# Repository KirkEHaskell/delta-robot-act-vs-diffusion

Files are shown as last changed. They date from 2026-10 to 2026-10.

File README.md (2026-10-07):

# ACT vs. Diffusion Policy on a Home-Built Delta Robot

**A real-robot comparison of the two most widely used imitation-learning policies, scaled across
training data (10–100 demonstrations) and training length (5k–50k steps), on a 3-DOF delta robot
with an electromagnet gripper. Everything is open: CAD, firmware, recording and evaluation code,
the 100-episode LeRobot dataset, 240 scored real-world trials, and the two best checkpoints.**

<p align="center">
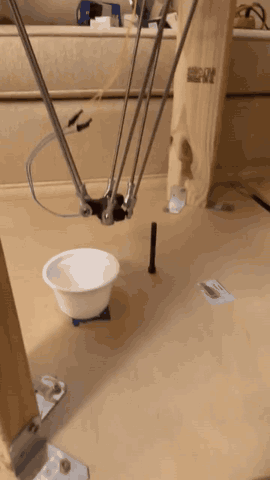
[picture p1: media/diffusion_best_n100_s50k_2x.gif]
Diffusion Policy (100 demos, 50k steps, 10/10 in scoring) picking up a bolt and dropping it in the cup, 2x speed
  
  &nbsp;&nbsp;
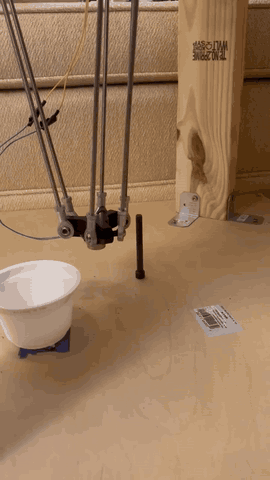
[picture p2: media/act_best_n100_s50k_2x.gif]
ACT (100 demos, 50k steps, 6/10 in scoring) picking up a bolt and dropping it in the cup, 2x speed
  
  <br>
  <sub>The two published models, fully autonomous, 2× speed, both trained on 100 demos for 50k steps and recorded after
  the study. Left: Diffusion Policy v2 (10/10 in scoring), RTX 3090. Right: ACT (6/10 in scoring), laptop CPU.
  Full-resolution clips: <a href="media/diffusion_best_n100_s50k.mp4">left</a>, <a href="media/act_best_n100_s50k.mp4">right</a>.
  Runs filmed during evaluation: <a href="media/diffusion_n25_s20k.mp4">Diffusion 25 demos / 20k</a>,
  <a href="media/act_n50_s20k.mp4">ACT 50 demos / 20k</a>.</sub>
</p>

<p align="center">
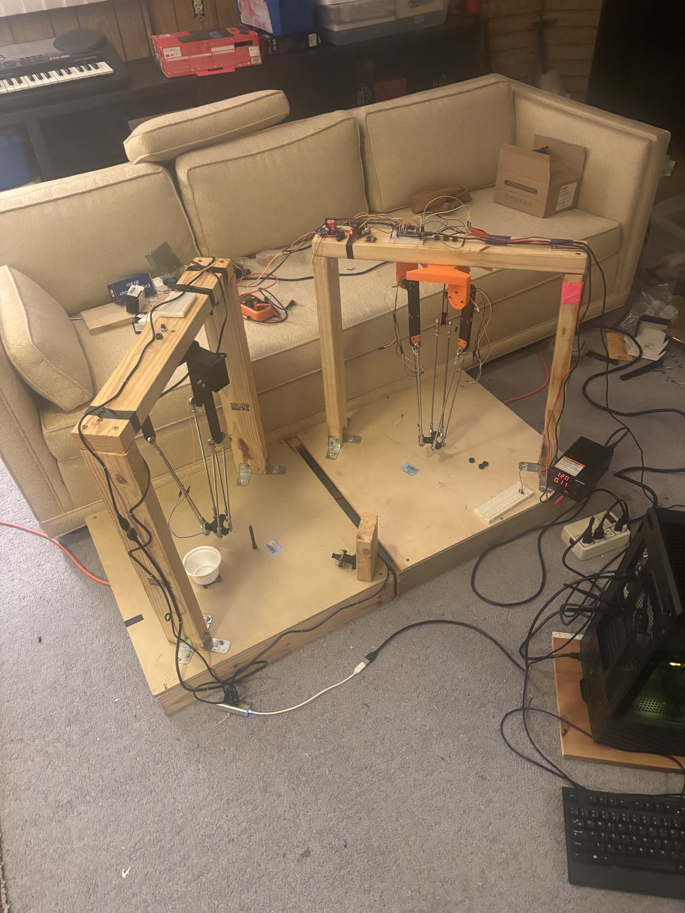
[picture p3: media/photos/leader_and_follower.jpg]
The follower robot (left, black, with the cup and bolt) and the hand-moved leader arm (right, orange mounts) side by side
  
  <br>
  <sub>The two robots. Left: the servo-driven follower that the policies control. Right: the leader arm, moved by hand
  during teleoperation, with a magnetic encoder at each shoulder.
  More photos: <a href="hardware/photos.md">hardware/photos.md</a>.</sub>
</p>

The task: find a steel bolt standing on the table, pick it up with the electromagnet, carry it to
a cup and drop it in. The policy sees three 320×240 USB cameras and outputs joint angles plus a
magnet on/off command at 30 Hz. There is no hand-written motion planning.

| | |
|---|---|
| Robot | 3-DOF delta robot, 3× Feetech STS3215 (12 V) servos, Teensy 4.1, electromagnet end effector |
| Teleoperation | Leader–follower: a second, hand-moved delta arm with 3× AS5600 magnetic encoders that the follower mirrors |
| Dataset | 100 demonstrations, 33,200 frames, 30 fps, 3 RGB cameras, LeRobot v3.0 format |
| Policies | ACT and Diffusion Policy, LeRobot 0.5.0 |
| Grid | {10, 25, 50, 100} demos × {5k, 20k, 50k} steps × 2 policies = 24 models |
| Evaluation | 10 real-robot trials per model (5 bolt positions × 2), **240 scored trials** |

📄 **Paper: [PDF](paper/ACT_vs_Diffusion_in_Delta_Robots_for_Simple_Pick_and_Place_Training.pdf)** (LaTeX source in [`paper/`](paper/)) · Markdown version: [REPORT.md](REPORT.md)

## Results at a glance

Success = the bolt ends up in the cup. 10 trials per cell.

| Demos | ACT 5k | ACT 20k | ACT 50k | Diffusion* 5k | Diffusion* 20k | Diffusion* 50k |
|---:|:---:|:---:|:---:|:---:|:---:|:---:|
| 10 | 0 | 0 | 0 | 0 | 0 | 2 |
| 25 | 0 | 6 | 2 | 1 | **8** | 5 |
| 50 | 1 | 6 | 5 | 2 | 4 | 1 |
| 100 | 0 | 3 | **6** | 0 | 6 | **10** |

<sub>*Diffusion Policy with four changes from LeRobot's defaults. The defaults did not work on this robot; see the first finding below.</sub>

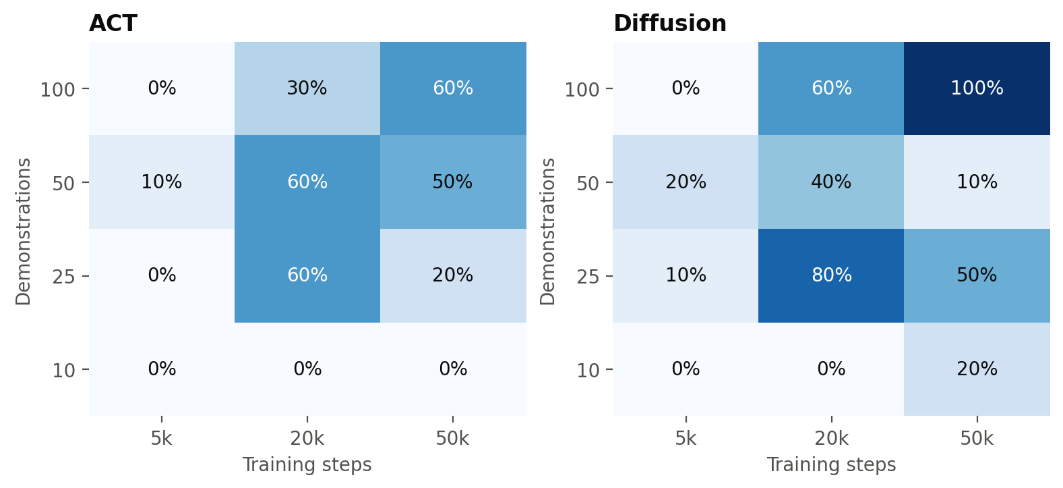
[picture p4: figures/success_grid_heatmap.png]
Success-rate heatmaps for ACT and Diffusion Policy


**Findings**

1. **Out of the box, LeRobot's Diffusion Policy never left the start pose.** With leader–follower
   teleoperation data, "next action ≈ current joint state" is almost exactly true. The default
   Diffusion setup (vision encoder trained from scratch, no crop augmentation, 2 observation frames,
   a 0.53 s horizon) learned to copy its own joint readings instead of looking at the cameras. Offline
   input-ablation tests showed this. Four changes fixed it: an ImageNet-pretrained ResNet-18, random crops,
   the joint-state input **blinded** (zeroed), and a 1.6 s action horizon. ACT, with its defaults, did
   not have this problem. If you train on leader–follower data, check for this shortcut.
2. **The best model was the fixed Diffusion Policy with 100 demos and 50k steps: 10/10**, every
   bolt position, every time on the first grab. Subjectively it was also the most impressive
   policy in the study. The operator's note was "just crushed it."
3. **Below about 20k steps or 25 demos, almost nothing works.** At 5k steps the two policies went 4/80
   combined, and with 10 demos 2/60.
4. **ACT improves steadily with more data** at 50k steps: 0 → 2 → 5 → 6 of 10 for 10/25/50/100 demos
   (trend p = 0.0015).
5. **There is no statistically significant overall winner.** Pooled over all 12 cells, Diffusion went
   39/120 and ACT 29/120 (Fisher p = 0.20). The two policies failed differently: ACT mostly knocked the
   bolt over (an aggressive grab); Diffusion mostly stalled (hesitation).
6. **ACT is the practical choice when speed matters.** It plans a 100-action chunk in about 0.1–0.4 s on a
   laptop CPU and runs in real time. Diffusion with 100 denoising steps needs about 0.76 s per
   24-action plan on an RTX 3090 (the robot pauses to think), and about 18 s on a laptop CPU.

Caveats: 10 trials per cell gives wide confidence intervals, and ACT and Diffusion were evaluated on
different machines on different days. [REPORT.md](REPORT.md) covers this in full.

## Models and dataset (Hugging Face)

| | Link | Trials | Notes |
|---|---|---|---|
| Dataset | [`KirkHaskell/delta_robot_bolt_pick_place`](https://huggingface.co/datasets/KirkHaskell/delta_robot_bolt_pick_place) | — | 100 episodes, LeRobot v3.0, 3 cameras, ~600 MB |
| Best Diffusion | [`KirkHaskell/diffusion_delta_robot_bolt_pick_place`](https://huggingface.co/KirkHaskell/diffusion_delta_robot_bolt_pick_place) | 10/10 | 100 demos, 50k steps; needs a GPU for real-time use |
| Best ACT | [`KirkHaskell/act_delta_robot_bolt_pick_place`](https://huggingface.co/KirkHaskell/act_delta_robot_bolt_pick_place) | 6/10 | 100 demos, 50k steps; runs on a laptop CPU |

The other 22 checkpoints (about 15 GB for the final checkpoints, about 250 GB with intermediate
checkpoints) are not published. Open an issue if you need one.

## What's in this repo

| Path | Contents |
|---|---|
| [`paper/`](paper/) | LaTeX source of the paper, its references and vector figures (`analysis/make_paper_figures.py`) |
| [`hardware/`](hardware/) | STL files for the printed parts and the Onshape assembly export (URDF + glTF meshes) |
| [`firmware/`](firmware/) | Teensy 4.1 firmware: leader–follower teleoperation, autonomous mode, electromagnet control |
| [`robot/`](robot/) | Record demonstrations, run a policy on the robot, scored evaluation sessions, camera and hardware checks (Windows + Linux) |
| [`training/`](training/) | Training queue for the whole grid, plus a LeRobot 0.5.0 wrapper (subset-sampler bug fix and joint-state blinding) |
| [`analysis/`](analysis/) | Results statistics and figures, the "copycat" diagnostic, DDIM-vs-DDPM check |
| [`results/`](results/) | All 240 trials, per-model summary, statistics, training-loss curves, ACT run traces |
| [`figures/`](figures/) | Plots used in the report |
| [`media/`](media/) | Robot videos and three example demonstrations (all three cameras side by side) |
| [`tools/`](tools/) | `render_episode.py`: turn any episode into a side-by-side video |

Example demonstrations from the dataset (left to right: `side`, `top_right`, `top_left`):
[episode 1](media/demos/episode_001.mp4) · [episode 42](media/demos/episode_042.mp4) · [episode 91](media/demos/episode_091.mp4)

## Quick start

Python 3.12 is recommended. Install PyTorch for your machine first (see pytorch.org), then:

```bash
git clone https://github.com/KirkEHaskell/delta-robot-act-vs-diffusion
cd delta-robot-act-vs-diffusion
pip install -r requirements.txt
```

**Download the dataset and the models**

```bash
hf download --repo-type dataset KirkHaskell/delta_robot_bolt_pick_place --local-dir data/delta_robot_bolt_pick_place
hf download KirkHaskell/act_delta_robot_bolt_pick_place --local-dir models/act
hf download KirkHaskell/diffusion_delta_robot_bolt_pick_place --local-dir models/diffusion
```

**Look at a demonstration** (needs ffmpeg)

```bash
python tools/render_episode.py --root data/delta_robot_bolt_pick_place --episode 42 --out episode_042.mp4
```

**Run a model on the robot** (from inside `robot/`, with the Teensy flashed and the cameras mapped; see [Building your own](#building-your-own))

```bash
cd robot
python teensy_check.py
python run_policy.py dry --ckpt ../models/act
python run_policy.py try --ckpt ../models/act
```

`dry` runs the model on live inputs and prints its actions without moving the robot. `try` runs it
for real: Enter starts a run and Space stops it. Diffusion: add `TC_SCHED=DDIM TC_STEPS=10` on a
CPU-only machine (much slower, but it works). The joint-state blinding the Diffusion model needs is
applied automatically.

**Train your own**

```bash
python training/run_grid.py --console          # the full ACT grid + default Diffusion (v1)
python training/run_grid.py --v2 --console     # the fixed Diffusion grid (v2)
```

Or train a single model with the same settings as the best Diffusion model:

```bash
BLIND_STATE=1 python training/lerobot_train_fixed.py \
  --dataset.repo_id=local/delta_robot_bolt_pick_place --dataset.root=data/delta_robot_bolt_pick_place \
  --dataset.video_backend=pyav --policy.type=diffusion --policy.push_to_hub=false \
  --policy.pretrained_backbone_weights=ResNet18_Weights.IMAGENET1K_V1 --policy.use_group_norm=false \
  "--policy.crop_shape=[216, 288]" --policy.crop_is_random=true --policy.n_obs_steps=1 \
  --policy.horizon=48 --policy.n_action_steps=24 --policy.drop_n_last_frames=24 \
  --batch_size=32 --seed=1000 --steps=50000 --output_dir=outputs/diffusion_v2_n100
```

For ACT, use `--policy.type=act` and drop the Diffusion-specific flags and `BLIND_STATE`. Training
used one RTX 3090. Expect about 3 h for 50k steps of either policy at batch size 32.

## Building your own

This repo is not a step-by-step build guide, but everything needed to reproduce the robot is here:

- **Printed parts:** [`hardware/stl/`](hardware/stl/) (base, upper arms, end effector with electromagnet
  mount, camera holders). [`hardware/onshape_export/`](hardware/onshape_export/) has the full assembly
  as URDF + glTF.
- **Electronics:**
  - Teensy 4.1
  - 3× Feetech STS3215 servos on a 1 Mbit/s bus (Teensy `Serial1`, servo IDs 2, 3, 1)
  - 3× AS5600 magnetic encoders on the leader arm (two hardware I²C buses + one bit-banged bus)
  - an electromagnet driven through an H-bridge (pins 30/32)
  - a push button for the magnet during teleoperation (pins 4/5)
  - 3× Innomaker U20CAM-720P USB cameras on a USB hub

  Pin assignments and calibration constants are at the top of
  [`firmware/delta_teleop/delta_teleop.ino`](firmware/delta_teleop/delta_teleop.ino).
- **Software setup:**
  1. Flash the firmware. Calibrate the encoders with the `d` debug command, as described in the
     firmware comments.
  2. Map each camera's USB port to its role in `robot/cameras_windows.py` or `robot/cameras_linux.py`.
     Run that file to list the ports.
  3. Check everything with `python robot/teensy_check.py` and `python robot/view_cameras.py`.
  4. Record demonstrations with `python robot/record_demos.py --root ../data/my_dataset`.
- **Serial protocol** (USB, 115200 baud):

  | Command | Meaning |
  |---|---|
  | `s` | Record/teleop mode |
  | `a` | Autonomous mode |
  | `c,j1,j2,j3,magnet` | Move command (autonomous mode) |
  | `x` | Stop |
  | `d` | Debug dump |

  The Teensy streams `millis,leader×3,follower×3,magnet` at 60 Hz. Joint angles are in degrees,
  clamped to 30–110°.

**Will the published checkpoints work on my robot?** Probably not without fine-tuning. They are tied
to this exact camera placement, table, lighting and camera colour settings. Treat them as a
reference point and as a starting point for fine-tuning on your own demos. The dataset and code are
the reusable parts.

**Camera colour:** in all of the training data, the `side` and `top_right` cameras have a
yellow-green cast. An old OpenCV script had turned auto white balance off and fixed the exposure,
and Windows kept those settings. The models expect this. On Linux, `run_policy.py` reproduces it
through V4L2 controls. For your own data, record with the cameras on auto
(`TC_MATCH_TRAINING_CAMERAS=0`).

## Lessons learned

- **Check that your policy actually uses the cameras.** [`analysis/diag_copycat.py`](analysis/diag_copycat.py)
  replays demos with the joint state frozen, then with the images frozen. A healthy policy
  reproduces the motion from images alone; a "copycat" doesn't. Low validation loss does not detect
  this.
- **Training loss predicts nothing here.** Fewer demos always gave lower loss (memorization) and
  worse robot performance.
- **LeRobot 0.5.x moved normalization out of the policy.** At inference you must load the
  checkpoint's pre/post-processors (`make_pre_post_processors`). Otherwise the actions come out
  normalized, and the arm drives into a joint limit.
- **LeRobot 0.5.0 bug:** Diffusion training with `--dataset.episodes` crashes, or silently reads the
  wrong frames. `training/lerobot_train_fixed.py` patches the sampler.
- **Three USB cameras on one hub need MJPG.** OpenCV on Windows silently falls back to uncompressed
  YUY2 and starves the third camera. Capture with PyAV and force MJPG.

## Citation

```bibtex
@misc{delta_act_vs_diffusion_2026,
  title  = {ACT vs. Diffusion Policy on a Home-Built Delta Robot: Data and Training-Length Scaling for Real-World Pick-and-Place},
  author = {Kirk Haskell},
  year   = {2026},
  url    = {https://github.com/KirkEHaskell/delta-robot-act-vs-diffusion}
}
```

## License

- **Code and firmware:** [MIT](LICENSE)
- **Dataset, CAD files, videos and figures:** [CC BY 4.0](LICENSE-DATA.md).
  Free to use, including commercially and for training models, with attribution.

Built with [LeRobot](https://github.com/huggingface/lerobot). The policies are
[ACT](https://arxiv.org/abs/2304.13705) (Zhao et al., 2023) and
[Diffusion Policy](https://arxiv.org/abs/2303.04137) (Chi et al., 2023).

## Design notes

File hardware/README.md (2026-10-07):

# Hardware

3D-printable parts and the full CAD assembly of the delta robot. This is not a step-by-step build
guide; see [photos.md](photos.md) and the videos in `media/` for how the parts go together.

## `stl/`: printed parts

| File | Part |
|---|---|
| `base_part1.stl`, `base_part2.stl` | Base, in two pieces |
| `upper_arm_6in_12mm.stl` | Upper arm driven by each servo ("Shoulder6in(12mm)" in the CAD); print 3 |
| `end_effector_electromagnet.stl` | End-effector platform with the electromagnet mount |
| `camera_holder.stl` | Camera mount |
| `camera_holder_base_mount.stl` | Camera mount that attaches to the base |

## `onshape_export/`

The Onshape assembly exported as **URDF + glTF meshes** (`assembly_1/urdf/assembly_1.urdf`, with a
ROS launch file). Delta robots are closed kinematic chains, so the URDF contains `*_loop_closure`
links from Onshape's export. Simulators that need a tree (e.g. plain ROS `robot_state_publisher`)
will only show the open part of each chain.

## Electronics (as built)

| Part | Notes |
|---|---|
| Teensy 4.1 | Runs `firmware/delta_teleop/delta_teleop.ino` |
| 3× Feetech STS3215 | Serial-bus servos on `Serial1` (TX pin 1 / RX pin 0), 1 Mbit/s, IDs 2, 3, 1 |
| 3× AS5600 magnetic encoder | Leader arm (teleoperation only). Two hardware I²C buses (`Wire`, `Wire2`) + one bit-banged bus on pins 20/21 |
| Electromagnet (~12 V) + H-bridge | IN1 = pin 30, IN2 = pin 32 |
| Push button | Magnet control during teleoperation, between pins 4 and 5 |
| 3× Innomaker U20CAM-720P | USB cameras on one hub, captured as MJPG 320×240 @ 30 fps |

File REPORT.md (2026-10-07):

# ACT vs. Diffusion Policy on a Home-Built Delta Robot: Data and Training-Length Scaling for Real-World Pick-and-Place

**Kirk Haskell** · October 2026 · Code, CAD, data and models: <https://github.com/KirkEHaskell/delta-robot-act-vs-diffusion>

---

## Abstract

We trained imitation-learning policies for a 3-DOF delta robot with an electromagnet gripper. The
task is to pick up a standing bolt and drop it into a cup. We compared **ACT** (Action Chunking with
Transformers) and **Diffusion Policy** along two axes: the amount of training data (10, 25, 50 or 100
teleoperated demonstrations) and the training length (5k, 20k or 50k optimizer steps). That is 24
models in total, each scored on 10 real-robot trials (240 trials).

Out of the box, LeRobot's default Diffusion Policy **did not move**. It had learned to copy the
robot's own joint state rather than use its cameras, a shortcut that leader–follower teleoperation
data makes very attractive. We diagnosed this with offline input-ablation tests and fixed it with
four changes:

- an ImageNet-pretrained vision encoder
- random-crop augmentation
- the joint-state input blinded (zeroed)
- a 1.6 s action horizon

With these changes, the best model, **Diffusion Policy with 100 demos and 50k steps, succeeded on
10/10 trials**. The best ACT models reached 6/10.

Both policies essentially failed with 10 demonstrations or with 5k training steps. ACT showed a
clean data-scaling trend at 50k steps (0 → 20 → 50 → 60%). Pooled over the grid, Diffusion succeeded
on 33% of trials and ACT on 24%, a difference that is not statistically significant (p = 0.20). The
two policies failed in different ways: ACT mostly knocked the bolt over, while Diffusion mostly
stalled. ACT ran in real time on a laptop CPU, while Diffusion needed a desktop GPU and paused while
planning.

---

## 1. Introduction

Imitation learning from teleoperated demonstrations is now the standard way to teach low-cost robot
arms manipulation skills. Two policy classes dominate open-source practice: ACT [1] and Diffusion
Policy [2], both implemented in Hugging Face's LeRobot library [3]. People adopting them face two
practical questions:

1. **How many demonstrations do I need?**
2. **How long should I train?**

Published comparisons mostly use standard arms (ALOHA, Franka, SO-100) and report a single
data/compute setting. This study measures a full 4 × 3 grid of data and training length for both
policies on a physically different robot, a **delta (parallel) robot**. It scores every model on the
real robot under a fixed protocol.

**Contributions**

- A controlled real-robot grid: 2 policies × 4 data sizes × 3 training lengths, 240 scored trials,
  with the raw trial log, statistics and code to regenerate every number.
- A documented failure mode: default Diffusion Policy learns a **proprioception "copycat" shortcut**
  from leader–follower data. The report gives an offline diagnostic for it and a fix.
- An open dataset (100 demonstrations, 3 cameras, LeRobot v3.0) for a delta robot with a binary
  magnetic gripper, an embodiment that is rare in public robot-learning datasets.
- Open hardware (STL/URDF), firmware, and recording/evaluation software.

## 2. System

### 2.1 Robot

- **Arm:** a 3-DOF delta robot. Three printed upper arms are driven by **Feetech STS3215** serial-bus
  servos, and steel parallelogram rods with ball joints connect them to the end effector.
- **End effector:** an electromagnet (~12 V) switched through an H-bridge, which lifts the steel bolt.
- **Controller:** a **Teensy 4.1** talks to the servos over a 1 Mbit/s half-duplex bus.
- **Joint limits:** commands are clamped to 30–110°.

Joint angles are reported in degrees. The firmware, 3D-printed parts and the Onshape assembly
(URDF + meshes) are in `firmware/` and `hardware/`.

### 2.2 Teleoperation

Demonstrations were collected **leader–follower**. The operator moves a passive leader arm whose
three joints carry **AS5600** magnetic encoders, and the Teensy drives the follower servos to the
same angles in real time. A push button on the leader switches the magnet. The Teensy streams
`(leader angles, follower angles, magnet state)` at 60 Hz, and the recorder samples it at 30 Hz.

### 2.3 Cameras

The robot uses three **Innomaker U20CAM-720P** USB cameras: `side`, `top_right` and `top_left`.
All three are captured at 320×240, 30 fps, MJPG. Two practical details mattered:

- **Bandwidth.** Three uncompressed (YUY2) streams saturate one USB hub. OpenCV's Windows backend
  cannot force MJPG, so capture goes through PyAV/ffmpeg with MJPG forced. Cameras are addressed by
  physical USB port rather than OS index, because the indices reshuffle on replug and all three
  cameras share one serial number.
- **Colour cast.** In all recorded data, `side` and `top_right` have a strong yellow-green cast. An
  old OpenCV script had disabled auto white balance (left at 4600 K) and fixed the exposure at
  2⁻⁶ s, and Windows persisted those settings per device. `top_left` ran on auto. The cast is
  constant across the dataset. For evaluation on Linux it was reproduced exactly through V4L2
  controls (`robot/cameras_linux.py`), verified by matching luma and chroma statistics against the
  training video.

## 3. Dataset

| Property | Value |
|---|---|
| Episodes / frames | 100 / 33,200 at 30 fps |
| Episode length | 8.1–17.3 s (median 10.7 s) |
| Observation | `observation.state` = 3 follower joint angles (deg); 3 RGB images, 240×320 |
| Action | 4-D: leader joint angles j1–j3 (deg) + magnet (0/1) |
| Task string | "pick up the bolt and drop it in the bucket" |
| Format | LeRobot v3.0, AV1 video, ~600 MB |
| Recorded | One operator, one day (2026-09-16), 10 sessions of 10 episodes |

Characteristics that matter for learning:

- **Single grasp per episode.** 99 of 100 demos have exactly one magnet press, so no retries are
  demonstrated. The magnet is on for a median of 3.6 s per demo.
- **Consistent start pose.** The mean start pose is (91.7, 93.2, 90.8)°, with a standard deviation
  of about 3.5° per joint.
- **Idle periods.** Each demo opens with a ~1.2 s idle (median 1.23 s), then a straight lift (95% of
  episodes move all three joints the same way, about −10° in the first 0.33 s). After the grab
  there is a median 0.33 s pause. These idle segments matter for Diffusion's stalling (Section 6.3).
- **Action is close to the current state.** Because the action is the leader angle and the state is
  the follower angle, the next action is always very close to the current state. This is the root
  of the copycat failure (Section 5).

**Training subsets** are nested and seeded. `random.Random(42).shuffle(range(100))` gives an order,
and the first N episodes form each subset, so n10 ⊂ n25 ⊂ n50 ⊂ n100. Frame counts are 3,219 /
8,380 / 16,326 / 33,200. The exact episode lists are in `training/run_grid.py`.

## 4. Training

### 4.1 Common settings

- **Software:** LeRobot 0.5.0, PyTorch 2.6.0, fp32.
- **Hardware:** one RTX 3090 (24 GB).
- **Fixed for every run:** batch size 32, seed 1000, 8 dataloader workers.
- **Hyperparameters:** policy defaults unless stated otherwise.

**Batch size.** Batch size 32 was chosen with smoke tests:

| Setting | Speed | GPU memory |
|---|---|---|
| ACT, b32 | 4.65 step/s | 6.4 GB |
| ACT, b64 | 2.2 step/s (fewer samples/s) | — |
| Diffusion, b32 | 3.64 step/s | 16 GB |
| Diffusion, b64 | does not fit | — |

**Mixed precision.** LeRobot 0.5.0 ignores `--policy.use_amp`, and bf16 through `accelerate` gave
no speedup, so all training is fp32.

**Training length.** The number of passes over the data (epochs = steps × 32 / frames) varies widely
across the grid:

| Demos | 5k steps | 20k steps | 50k steps |
|---:|---:|---:|---:|
| 10 | 50 | 199 | 497 |
| 25 | 19 | 76 | 191 |
| 50 | 10 | 39 | 98 |
| 100 | 5 | 19 | 48 |

### 4.2 ACT

LeRobot defaults:

- ResNet-18 backbone with ImageNet weights
- 1 observation frame
- chunk size 100, all 100 actions executed before re-planning (no temporal ensembling)
- VAE with KL weight 10
- constant learning rate 1e-5

Because the learning rate is constant, **one 50k-step run per data size** was trained, and its
checkpoints at 5k and 20k steps serve as the shorter-training cells. They are identical to what
separate 5k and 20k runs would produce.

### 4.3 Diffusion Policy, v1 (LeRobot defaults)

- ResNet-18 trained from scratch with GroupNorm, no crop augmentation
- 2 observation frames
- horizon 16, 8 executed actions
- DDPM with 100 steps
- cosine learning-rate schedule

Because the cosine schedule depends on total steps, **each cell is a separate run**.

### 4.4 Diffusion Policy, v2 (used for all scored Diffusion results)

| Setting | v1 (default) | v2 |
|---|---|---|
| Vision backbone | ResNet-18 from scratch, GroupNorm | ResNet-18 **ImageNet-pretrained**, BatchNorm |
| Augmentation | none | **random crop** 216×288 |
| Observation frames | 2 | **1** |
| Joint-state input | used | **blinded** (zeroed after normalization, in training and at inference) |
| Horizon / executed actions | 16 / 8 (0.53 s / 0.27 s) | **48 / 24 (1.6 s / 0.8 s)** |

The 48/24 horizon reproduces the original Diffusion Policy paper's 1.6 s / 0.8 s timing (16/8 steps
at 10 Hz), rescaled to this dataset's 30 Hz. Everything else matched v1: batch size, seed, cosine
schedule, the same subsets, and one run per cell. Why these changes were needed is explained in
Section 5.

### 4.5 Training cost

| Grid | Wall time per 50k-step run |
|---|---|
| ACT | ~3.1–3.4 h |
| Diffusion v1 | ~3.8–4.3 h |
| Diffusion v2 | ~3.0–3.2 h |

All 28 grid runs (ACT 4, Diffusion v1 12, Diffusion v2 12) completed without failures, and the
training loss decreased in every run.

Two training-side observations:

- **Fewer demos always gave lower training loss.** For example, at the end of training, Diffusion v2
  reached a loss of 0.0019 with 10 demos versus 0.0061 with 100 demos. This is memorization, and it
  is the opposite of the robot-success ordering.
- **Training loss is not comparable between the policies.** ACT's loss is L1 + KL; Diffusion's is a
  noise-prediction MSE.

Loss curves for every run are in `results/training/`.

### 4.6 A LeRobot 0.5.0 bug

With `--dataset.episodes` (subset training), Diffusion's `EpisodeAwareSampler` yields absolute frame
indices into a dataset that is indexed relative to the subset. This crashes training
(`IndexError: … out of bounds for size 3219`) or reads the wrong frames. `training/lerobot_train_fixed.py`
remaps the sampler indices. It is a no-op for ACT and for the full dataset. Every run in this study
used the wrapper.

## 5. The "copycat" failure of default Diffusion Policy

**Symptom.** On the real robot, every v1 Diffusion checkpoint **held still at the start pose**.
Changing inference did not help:

- GPU vs CPU
- DDIM-10 vs DDPM-100
- fixed initial noise
- longer executed chunks
- a scripted "kick-start" lift (the arm moved briefly, then stopped again)

ACT checkpoints on the same rig moved normally.

**Diagnosis** (`analysis/diag_copycat.py`, offline, on training episodes):

- **Teacher-forced replay looked perfect** (about 0.4° error), so the training loss and replay error
  revealed nothing.
- **Images only.** With the images playing the demo and the joint state frozen at frame 0, ACT
  reproduced **92%** of the demo's motion range. v1 Diffusion reproduced **37%**.
- **State only.** With the images frozen and the state moving, v1 Diffusion followed the state. It
  was predicting "next action ≈ current joint state (+ velocity from the two observation frames)."
- **Closed loop from a still start.** With the robot still at the start pose and the cameras
  showing the first frame, v1 Diffusion (50 demos, 50k steps) commanded less than 1° of motion. It
  never starts, because a still robot predicts a still robot. **Longer training made this worse.**

**Why Diffusion and not ACT?** In leader–follower teleoperation, the action (leader angle) is
always within a fraction of a degree of the next state (follower angle). Copying proprioception is
therefore a near-perfect predictor over short horizons. LeRobot's default Diffusion setup has
several properties that make that shortcut win:

- a randomly initialized vision encoder
- no augmentation
- two state frames, which give the policy velocity
- a short 0.53 s horizon, over which copying the current state is almost always right

ACT's ImageNet-pretrained backbone, single frame and 3.3 s chunks force it to use the images.

**Pilot fixes** (all 50 demos, 5k steps):

| Variant | Change | Images-only motion | On the robot |
|---|---|---:|---|
| v1 default | — | 37% | stalls |
| + pretrained vision | ImageNet ResNet-18 + BatchNorm, random crop, 1 obs frame | 42% | stalls |
| + state blinded | joint state zeroed in training and inference | 96% | moves and grabs, but jittery and hesitant |
| **+ 1.6 s horizon (v2)** | horizon 48, execute 24 | 95% | **completed a pick-and-place** |

Blinding the state was the decisive change. The longer horizon removed most of the jitter. After
full training, v2 models were 99–100% image-driven by this diagnostic.

**Takeaway for practitioners and dataset builders:** leader–follower data invites state-copying. A
low training loss or a good teacher-forced replay does not rule it out. An images-only ablation
does, and it takes minutes to run.

## 6. Robot evaluation

### 6.1 Protocol

- **Positions and trials.** Five bolt positions (P1–P5) are marked on the table, and each model
  gets 2 tries per position, for **10 trials per model**. The cup position, lighting and camera setup
  are fixed.
- **Where the positions are.** P1, P2 and P3 are inside the area covered by the demonstrations. P4
  is inside it but partly hidden by the cup and awkward for the robot to reach. **P5 is outside
  the demonstrated area** but easy to reach.
- **Start of each trial.** The arm glides to the dataset's mean start pose with the magnet off, then
  the policy runs at 30 Hz.
- **End of each trial.** A trial ends when the operator stops it or after 900 executed actions
  (30 s of motion).
- **Scoring.** The operator recorded:
  - *Picked up* (Y/N)
  - *In cup* (Y/N), the success metric
  - *grab attempts* (the number of times the magnet switched on, printed by the script)
  - a *failure mode*: knocked bolt over, stalled or timed out, dropped in transit, missed cup, or
    unsafe (the operator stopped erratic motion)
- **Unsafe stops count as failures.** The excluded-Unsafe convention is also reported in
  `results/results_by_model.csv`.
- **Model order.** Models were tested in a seeded random order (seeds 1074 and 8796,
  `results/test_order/`), so that time-of-day drift does not line up with data size or training
  length.

**ACT evaluation:**

- Windows laptop (AMD Ryzen AI 9 HX 370, CPU only), LeRobot 0.5.2 (it loads 0.5.0 checkpoints
  unchanged)
- ACT plans a 100-action chunk in 0.1–0.37 s
- the measured control loop ran at 29.3–29.9 Hz

**Diffusion v2 evaluation:**

- Linux desktop (RTX 3090), DDPM with all 100 denoising steps, as trained
- about **0.76 s per 24-action plan**; the robot pauses while it plans (acceptable for this
  quasi-static task)
- the Windows colour cast reproduced through V4L2
- the joint state blinded at inference

On the laptop CPU, Diffusion would have needed about 18 s per plan (DDPM-100), or 2 s with DDIM-10.

### 6.2 Results

**Success (bolt in cup), out of 10 trials:**

| Demos | ACT 5k | ACT 20k | ACT 50k | Diff v2 5k | Diff v2 20k | Diff v2 50k |
|---:|:---:|:---:|:---:|:---:|:---:|:---:|
| 10 | 0 *(10 unsafe)* | 0 *(2 unsafe)* | 0 | 0 *(10 unsafe)* | 0 *(2 unsafe)* | 2 |
| 25 | 0 *(2 unsafe)* | 6 | 2 | 1 *(2 unsafe)* | **8** | 5 |
| 50 | 1 *(4 unsafe)* | 6 *(1 unsafe)* | 5 | 2 *(2 unsafe)* | 4 | 1 |
| 100 | 0 *(10 unsafe)* | 3 | **6** | 0 *(2 unsafe)* | 6 | **10** |

95% Wilson intervals for 10 trials are wide:

| Successes | Interval |
|---:|---|
| 6/10 | 31–83% |
| 8/10 | 49–94% |
| 10/10 | 72–100% |

Per-model intervals, pick rates and failure counts are in `results/results_by_model.csv`.

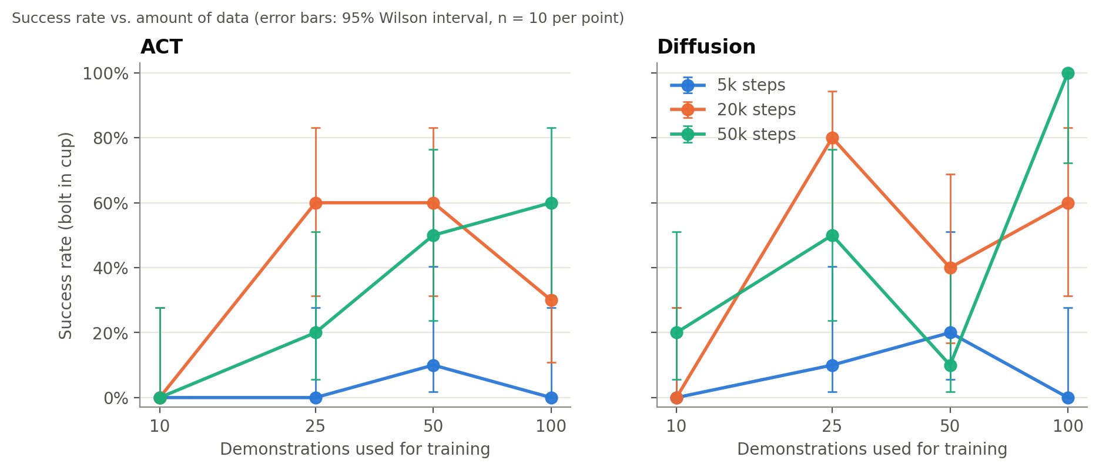
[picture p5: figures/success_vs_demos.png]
Success vs. demonstrations


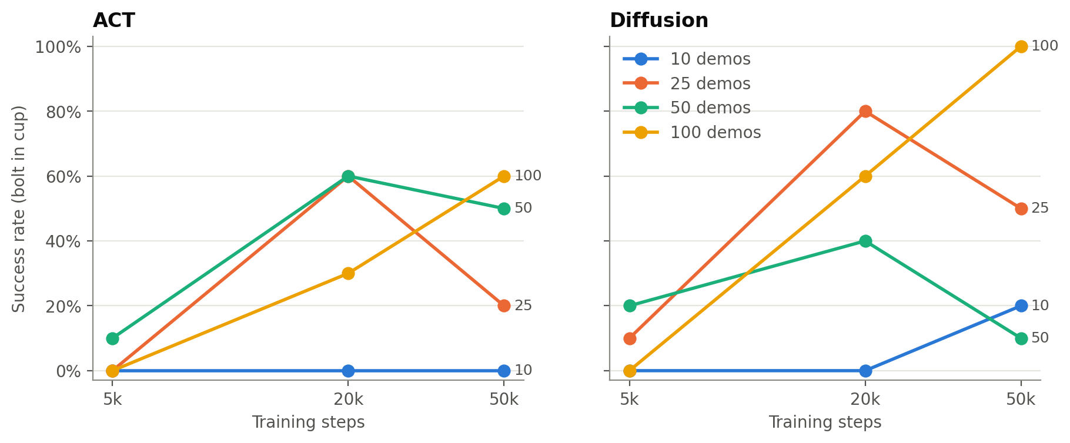
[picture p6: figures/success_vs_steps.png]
Success vs. training steps


**Statistics** (full output in `results/stats_output.txt`):

| Comparison | Result | p |
|---|---|---|
| ACT, data trend at 50k steps (Cochran–Armitage) | 0, 2, 5, 6 of 10 | 0.0015 |
| ACT, training-length trend at 100 demos | 0, 3, 6 of 10 | 0.004 |
| Diffusion v2, training-length trend at 100 demos | 0, 6, 10 of 10 | < 0.0001 |
| Diffusion v2, data trend at 50k steps | 2, 5, 1, 10 of 10 | 0.005 (not monotone) |
| ACT vs Diffusion, pooled over all 12 cells (Fisher) | 29/120 vs 39/120 | 0.20 |
| ACT vs Diffusion, best cell (100 demos, 50k) | 6/10 vs 10/10 | 0.087 |

**Clustering caveat:** the two tries at the same position agreed in 88% of pairs, so each model's 10
trials carry roughly the information of 5 independent outcomes. All p-values above should be read as
optimistic.

### 6.3 How the policies fail

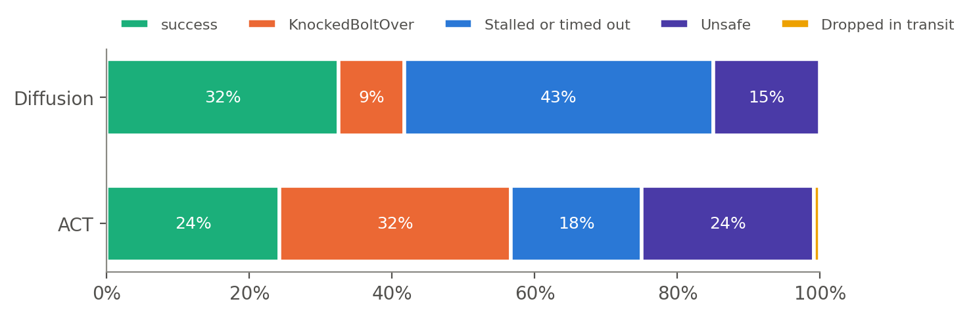
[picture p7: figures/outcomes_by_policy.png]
Outcomes by policy


| Outcome (of 120 trials) | ACT | Diffusion v2 |
|---|---:|---:|
| Success | 29 | 39 |
| Knocked bolt over | 39 | 11 |
| Stalled or timed out | 22 | 52 |
| Unsafe (operator stop) | 29 | 18 |
| Dropped in transit | 1 | 0 |

- **ACT fails aggressively.** It drives down to the bolt and grabs imprecisely, knocking the
  standing bolt over. Undertrained ACT (5k steps) was erratic enough that both the 10-demo and the
  100-demo models were stopped as unsafe on every trial.
- **Diffusion v2 fails hesitantly.** It hovers or freezes, most often before the grab. This matches
  the idle segments in the demonstrations (the ~1.2 s still start and the pause after grabbing). With
  the joint state blinded, a still camera view is ambiguous between "about to move" and "waiting,"
  and an undertrained model can stay in the waiting mode. The 10-demo, 5k-step Diffusion model was
  stopped as unsafe on all 10 trials.

### 6.4 Bolt position

| Position | Where | ACT successes | Diffusion v2 successes | Unsafe stops (ACT / Diff) |
|---|---|---:|---:|---:|
| P1 | in demos | 8/24 | 7/24 | 4 / 2 |
| P2 | in demos | 9/24 | 12/24 | 4 / 2 |
| P3 | in demos | 3/24 | 8/24 | 4 / 2 |
| P4 | in demos, partly hidden by the cup, awkward to reach | 1/24 | 7/24 | 11 / 10 |
| P5 | **outside** the demos | 8/24 | 5/24 | 6 / 2 |

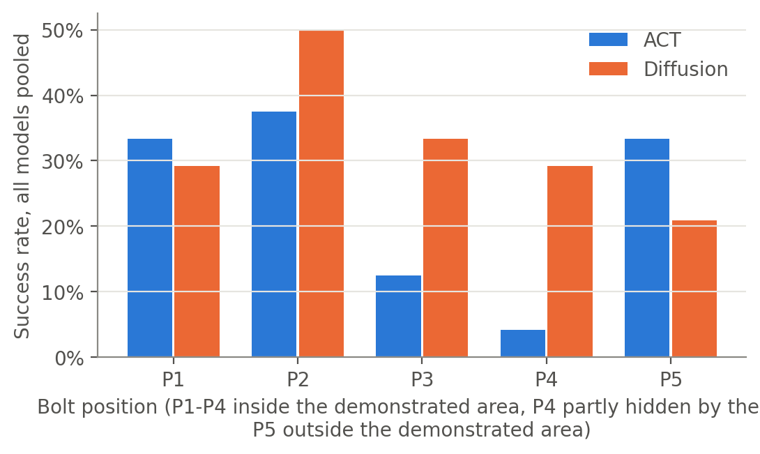
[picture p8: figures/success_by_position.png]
Success by bolt position


- **P4** produced 21 of the 47 unsafe stops. It is the hardest position for both policies, and
  nearly impossible for ACT. Diffusion handled it much better (7 vs 1).
- **P5 (out of distribution)** was not the hardest position. The 100-demo ACT models went 2/2 at P5
  at both 20k and 50k steps, and the best Diffusion model went 2/2 there too. With a single
  bolt-and-cup layout, generalizing a few centimetres outside the demonstrated area appears easier
  than handling partial occlusion.
- **An unexplained ACT result:** both 100-demo ACT models failed at P1, the most heavily
  demonstrated position, while the 50-demo ACT models succeeded there. A plausible but untested
  explanation: ACT's latent variable is fixed to its mean at test time, so many slightly different
  P1 grabs average into one that is a few millimetres off. The magnet needs near-contact.

### 6.5 The best model

**Diffusion v2, 100 demos, 50k steps: 10/10.** It succeeded at every position, including the
out-of-distribution P5 and the occluded P4, and **every trial needed only one grab attempt**.
Subjectively it was the standout of the study, and the operator's note was "just crushed it."

The best ACT models scored 6/10:

| Model | Notes |
|---|---|
| 100 demos, 50k | no unsafe stops; succeeded at P2, P3, P5 |
| 50 demos, 20k | — |
| 25 demos, 20k | fewest grab attempts; succeeded at 4 of 5 positions |

The 100-demo, 50k ACT is published as the reference ACT model because it ran in real time on a
laptop CPU and was never stopped as unsafe.

## 7. Discussion

- **Training length is the first gate.** At 5k steps, neither policy is usable (4/80 combined),
  regardless of data. For ACT at 100 demos this is only 5 epochs. Given enough steps, more data
  helps both policies, most clearly at 50k steps.
- **Overtraining at small and medium data is possible.** At 25 demos, both policies did better at
  20k than at 50k (ACT 6 → 2, Diffusion 8 → 5), and Diffusion at 50 demos dropped from 4 to 1. No
  single drop is significant at n = 10, but the direction repeats three times while training loss
  keeps falling. At 100 demos, longer training only helped. A reasonable heuristic from this data is
  to scale training steps with dataset size rather than train small datasets for longer. This
  remains a hypothesis.
- **Policy choice is a trade-off, not a clear win.**
  - Modified Diffusion produced the single best model and handled the occluded position far better.
  - ACT was competitive in the middle of the grid (6/10 at three settings), ran in real time on a
    laptop CPU, and needed no architectural changes.
  - Pooled, the 10-percentage-point gap in Diffusion's favour is within noise.
- **Proprioception is a liability with leader–follower data,** at least for Diffusion Policy with
  short horizons. The same data trained ACT fine, but ACT's loss of P1 precision at 100 demos hints
  that it may be leaning on state as well. A proprioception ablation for ACT is the obvious next
  experiment.
- **The Diffusion stalling probably comes from the data.** Trimming idle frames from the
  demonstrations, or conditioning on a short observation history of images only, would likely
  reduce it.

## 8. Limitations and threats to validity

- **Different conditions for the two policies.** ACT ran on a Windows laptop CPU on Oct 2–3.
  Diffusion v2 ran on a Linux GPU desktop on Oct 5, after the hardware repairs listed below.
  The randomized order held within each policy but not across them, so day-to-day drift could align
  with policy. The camera colour cast was native on Windows and reproduced on Linux.
- **Diffusion v2 is not stock Diffusion Policy.** It has no proprioception, a pretrained encoder, crop
  augmentation and a longer horizon. ACT used stock settings with proprioception. Stock Diffusion
  (v1) was not formally scored; it never completed a pick in informal testing.
- **Small samples.** 10 trials per model, 5 positions, with strong within-position clustering
  (Section 6.2).
- **Scoring was not blind.** The operator knew which model was running.
- **One training seed per cell** (seed 1000). Seed-to-seed variance was not measured.
- **Hardware events during ACT testing:**
  - a printed upper arm broke on Oct 2 and was replaced with an identical part; a known-good model
    behaved the same afterwards
  - a damaged leader-encoder cable disrupted the shared bus on Oct 3; it was fixed by unplugging the
    leader encoders, which are unused in autonomous mode
  - the firmware then stalled on reads of the missing encoders until it was patched to skip them in
    autonomous mode; no scored run comes from the slow period, and all logged runs ran at about 29.5 Hz
  - a loose magnet wire was found and fixed
- **Scene drift.** The background had shifted between recording and testing, and it was restored
  using the demonstration videos as reference before evaluation.
- **Data-entry notes.** "Grab attempts" was often entered as 10 for stalled runs, so treat it as
  approximate. The 10 trials of Diffusion v2 (10 demos, 5k steps) were logged after the main session
  as all-unsafe.

## 9. Conclusion

On a home-built delta robot doing pick-and-place:

- Both ACT and Diffusion Policy need roughly **≥ 25 demonstrations and ≥ 20k training steps** before
  they work at all.
- **More data pays off most with long training.**
- The two policies **fail in characteristically different ways.**
- **Default Diffusion Policy can silently learn to ignore its cameras** when trained on
  leader–follower data. A simple ablation exposes this, and blinding proprioception fixes it.
- With that fix, Diffusion Policy trained on 100 demonstrations for 50k steps solved the task in
  **10 out of 10** trials.

**Future work:**

- more trials per cell, with blind scoring
- multiple training seeds
- a proprioception ablation for ACT
- trimming idle frames from the demonstrations
- temporal ensembling for ACT
- real-time Diffusion inference (fewer denoising steps or consistency distillation)

## Reproducibility

| What | Where |
|---|---|
| Every trial | `results/robot_trials.csv` |
| Regenerate all statistics and figures | `python analysis/analyze_results.py` |
| Training | `training/run_grid.py` (`--v2` for the fixed Diffusion grid) |
| Robot evaluation | `robot/run_policy.py` (`plan` / `run` / `try` / `summary`) |
| Copycat diagnostic | `analysis/diag_copycat.py` |
| Dataset and best checkpoints | Hugging Face (links in the README) |

## References

1. T. Z. Zhao, V. Kumar, S. Levine, C. Finn. *Learning Fine-Grained Bimanual Manipulation with
   Low-Cost Hardware* (ACT). RSS 2023. arXiv:2304.13705
2. C. Chi, S. Feng, Y. Du, Z. Xu, E. Cousineau, B. Burchfiel, S. Song. *Diffusion Policy:
   Visuomotor Policy Learning via Action Diffusion*. RSS 2023. arXiv:2303.04137
3. R. Cadene et al. *LeRobot: State-of-the-art Machine Learning for Real-World Robotics in PyTorch*.
   https://github.com/huggingface/lerobot, 2024

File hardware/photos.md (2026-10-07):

# Photos

| | |
|---|---|
| Leader and follower | Follower robot (left, does the task) and leader arm (right, moved by hand) |
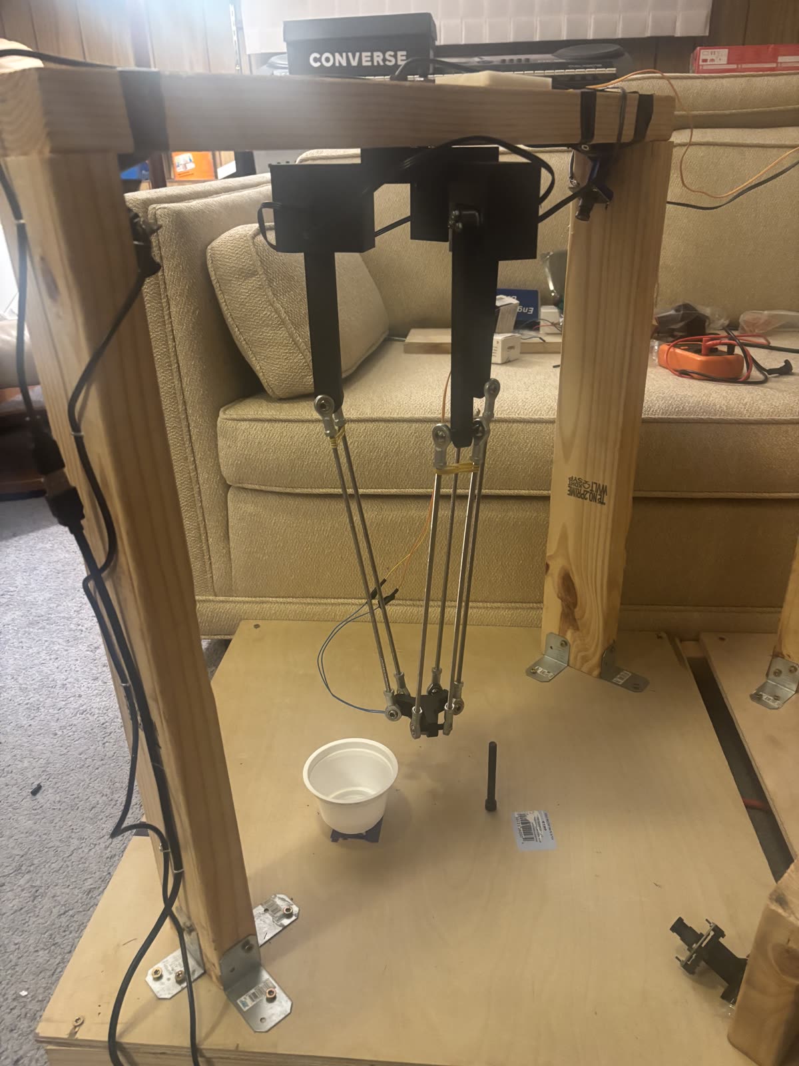
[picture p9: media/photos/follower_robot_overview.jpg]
Follower
|  | Follower: three STS3215 servos at the top, parallelogram rods down to the electromagnet end effector; cup and bolt on the table |
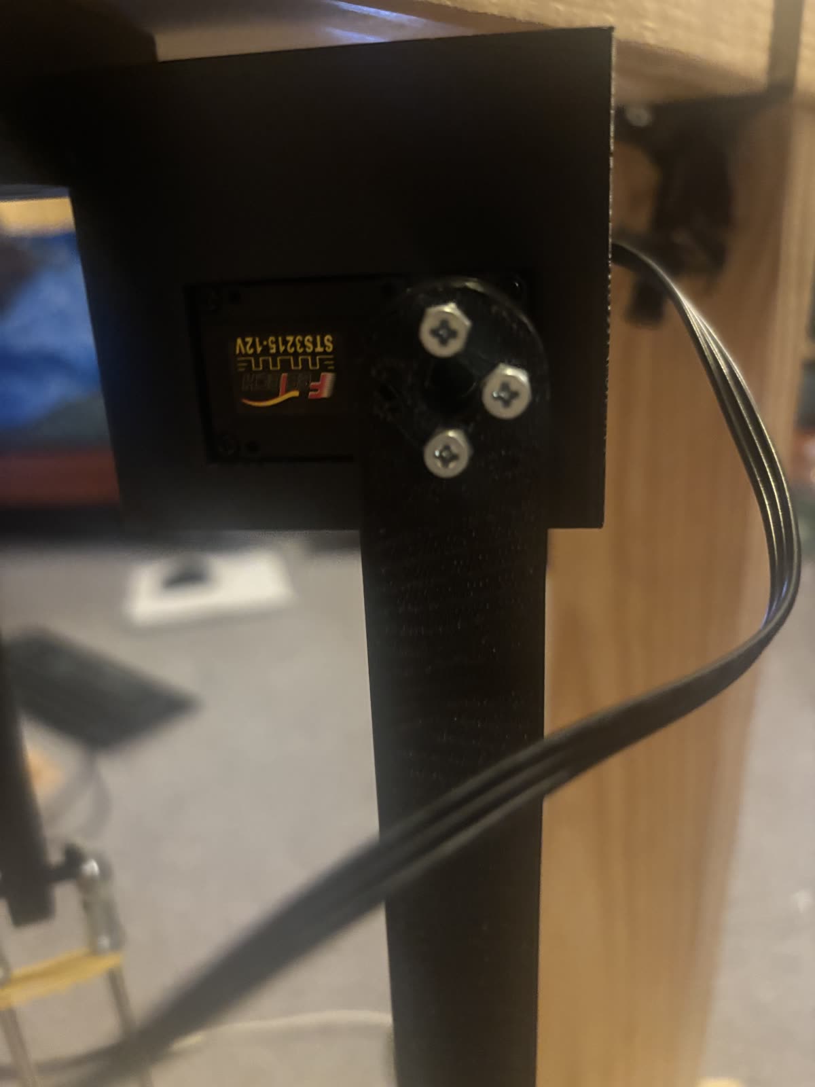
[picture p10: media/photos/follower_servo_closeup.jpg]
Follower servo
|  | Follower shoulder: Feetech STS3215 (12 V) servo and upper arm |
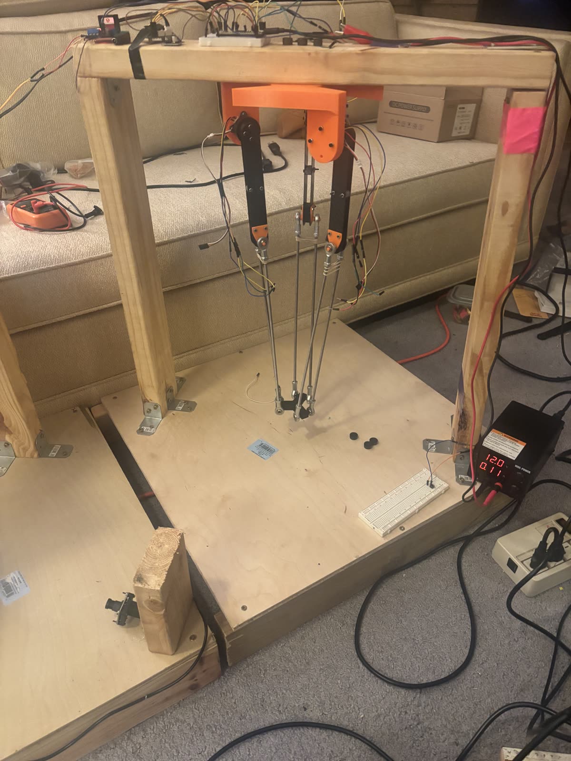
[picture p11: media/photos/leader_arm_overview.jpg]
Leader
|  | Leader arm in its frame, with the electronics on top |
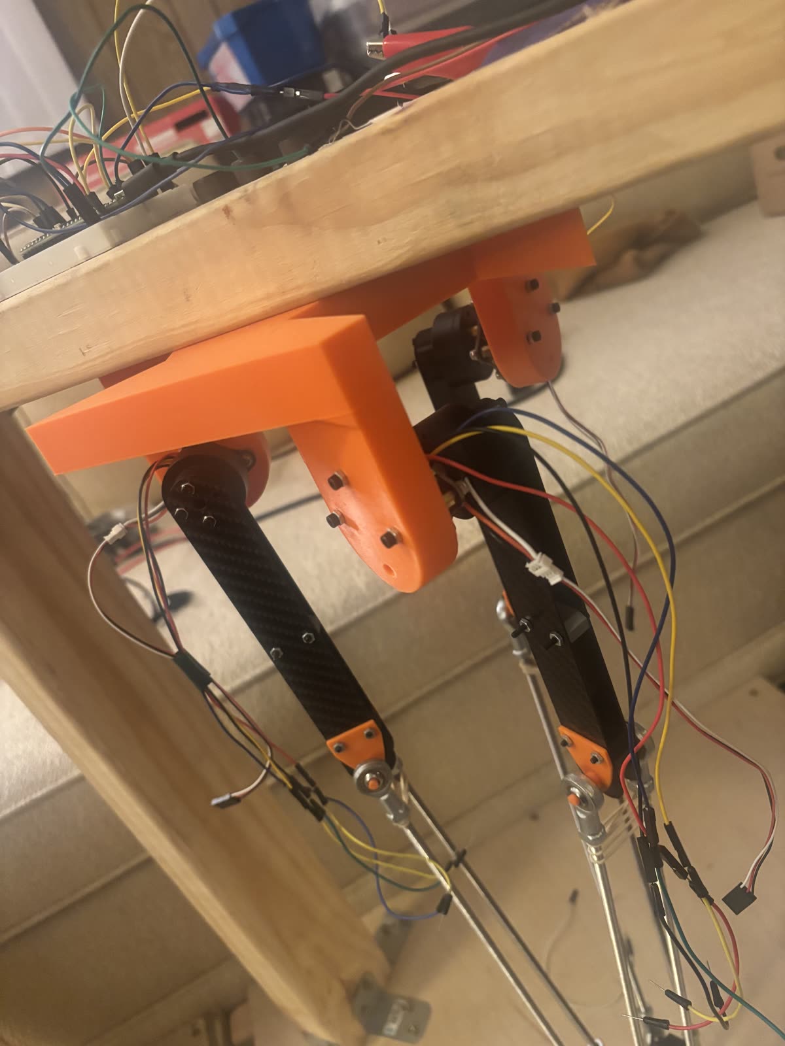
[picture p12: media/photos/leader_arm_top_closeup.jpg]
Leader shoulder
|  | Leader shoulders: printed mounts with an AS5600 magnetic encoder on each joint |
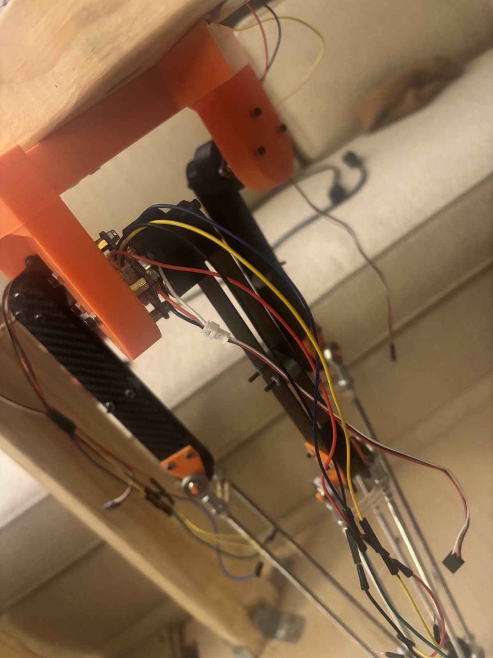
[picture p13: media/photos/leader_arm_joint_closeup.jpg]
Leader joint
|  | Leader joint close-up |

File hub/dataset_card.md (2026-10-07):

---
license: cc-by-4.0
task_categories:
- robotics
tags:
- LeRobot
- imitation-learning
- teleoperation
- delta-robot
- parallel-robot
- pick-and-place
- electromagnet
- real-world
- multi-view
pretty_name: Delta Robot Bolt Pick-and-Place (3 cameras, 100 demos)
size_categories:
- 10K<n<100K
configs:
- config_name: default
  data_files: data/*/*.parquet
---

# Delta Robot Bolt Pick-and-Place: 100 teleoperated demonstrations, 3 cameras

100 real-world demonstrations of a **3-DOF delta (parallel) robot** with an **electromagnet
gripper**. In each one, the robot picks up a standing steel bolt and drops it into a cup. The data
was recorded by leader–follower teleoperation and is stored in **LeRobot v3.0** format.

This is the dataset behind the study *ACT vs. Diffusion Policy on a Home-Built Delta Robot*
(240 scored real-robot trials, 24 trained models). Code, CAD, firmware and the full report are at
<https://github.com/KirkEHaskell/delta-robot-act-vs-diffusion>.

## At a glance

| | |
|---|---|
| Robot | 3-DOF delta robot (`robot_type: delta_3dof`), 3× Feetech STS3215 servos, Teensy 4.1 |
| Gripper | Electromagnet, binary on/off |
| Episodes / frames | 100 / 33,200 |
| Frequency | 30 Hz |
| Episode length | 8.1–17.3 s (median 10.7 s) |
| Cameras | `side`, `top_right`, `top_left`: 240×320 RGB, AV1 video |
| Task string | `"pick up the bolt and drop it in the bucket"` (single task) |
| Teleoperation | Leader–follower; the leader is a hand-moved arm with AS5600 magnetic encoders |
| License | CC BY 4.0. Commercial use and use in training data are fine, with attribution |

## Features

| Key | Shape | Meaning |
|---|---|---|
| `observation.state` | (3,) float32 | Follower (robot) joint angles j1, j2, j3 in **degrees** (servo frame, ~90° = arm horizontal; usable range 30–110°) |
| `action` | (4,) float32 | Leader joint angles j1, j2, j3 in **degrees** + `mag`, the magnet command (0 = off, 1 = on) |
| `observation.images.side` | (240, 320, 3) | Side view |
| `observation.images.top_right` | (240, 320, 3) | Overhead view, right |
| `observation.images.top_left` | (240, 320, 3) | Overhead view, left |

The actions are **absolute joint-space targets**, not Cartesian poses and not deltas. The robot's
firmware clamps them to 30–110° and drives the servos to them directly.

## Things you should know before using it

- **Action ≈ next state.** Because of leader–follower teleoperation, the action (leader angle) is
  always very close to the next observed state (follower angle). In this study, LeRobot's default
  Diffusion Policy exploited this and learned to copy the joint state instead of using the
  cameras. The robot never moved. Blinding the state input fixed it. If you train on this data,
  check that your policy is image-driven.
- **Colour cast.** The `side` and `top_right` cameras have a constant yellow-green cast in every
  episode (auto white balance off, fixed exposure). `top_left` is neutral. The cast is consistent
  across all 100 episodes.
- **Idle segments.** Each episode starts with about 1.2 s of stillness, and there is a short pause
  (median 0.33 s) after the magnet grabs.
- **One grasp per episode.** 99 of 100 episodes contain exactly one magnet activation. No failed
  grasps or retries are demonstrated.
- **Single scene.** One table, one cup position, bolt placed at various spots within a demonstrated
  region. The lighting is indoor and roughly constant.
- **One operator, one robot,** recorded on one day (2026-09-16, about 15:30–19:15) in 10 sessions of 10 episodes.

## Quick start

```python
from lerobot.datasets.lerobot_dataset import LeRobotDataset

ds = LeRobotDataset("KirkHaskell/delta_robot_bolt_pick_place", video_backend="pyav")
frame = ds[0]
print(frame["observation.state"], frame["action"], frame["observation.images.side"].shape)
```

The study trained on nested subsets of 10/25/50/100 episodes. The exact episode lists are in
`training/run_grid.py` in the GitHub repo.

## Results obtained with this data (10 real-robot trials per model)

| Model | Trained on | Success |
|---|---|---|
| Diffusion Policy (pretrained ResNet-18, crop augmentation, state blinded, 1.6 s horizon), 50k steps | all 100 episodes | **10/10** |
| ACT (LeRobot defaults), 50k steps | all 100 episodes | 6/10 |
| Either policy, 10 episodes or 5k steps | — | ≤ 2/10 |

Full grid and analysis: see the GitHub repo.

## Citation

```bibtex
@misc{delta_act_vs_diffusion_2026,
  title  = {ACT vs. Diffusion Policy on a Home-Built Delta Robot: Data and Training-Length Scaling for Real-World Pick-and-Place},
  author = {Kirk Haskell},
  year   = {2026},
  url    = {https://github.com/KirkEHaskell/delta-robot-act-vs-diffusion}
}
```

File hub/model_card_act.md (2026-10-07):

---
license: mit
library_name: lerobot
pipeline_tag: robotics
tags:
- LeRobot
- act
- imitation-learning
- delta-robot
- pick-and-place
- real-world
datasets:
- KirkHaskell/delta_robot_bolt_pick_place
---

# ACT: delta robot bolt pick-and-place (100 demos, 50k steps)

An [ACT](https://arxiv.org/abs/2304.13705) policy trained with LeRobot 0.5.0 on all 100
demonstrations of [`KirkHaskell/delta_robot_bolt_pick_place`](https://huggingface.co/datasets/KirkHaskell/delta_robot_bolt_pick_place).
It drives a home-built 3-DOF delta robot with an electromagnet gripper: it picks up a standing bolt
and drops it into a cup.

**Real-robot result: 6/10 successes** (95% Wilson CI 31–83%). It was tied for the best ACT model in
a 12-model ACT grid, and it was never stopped as unsafe. Its failures were 4 stalls or timeouts. It
succeeded at both out-of-distribution trials (bolt outside the demonstrated area). Full study:
<https://github.com/KirkEHaskell/delta-robot-act-vs-diffusion>

| | |
|---|---|
| Inputs | `observation.state` (3 joint angles, deg) + 3 cameras (`side`, `top_right`, `top_left`, 240×320) |
| Output | 4-D action: 3 absolute joint targets (deg) + magnet (on if > 0.5) |
| Settings | LeRobot ACT defaults: ResNet-18 (ImageNet), chunk size 100, all 100 actions executed, VAE (KL weight 10), LR 1e-5 |
| Training | 50k steps, batch 32, seed 1000, fp32, one RTX 3090 (~3.1 h) |
| Inference speed | 0.1–0.37 s per 100-action chunk on a laptop CPU (Ryzen AI 9 HX 370), real time at 30 Hz |

## Use

```bash
hf download KirkHaskell/act_delta_robot_bolt_pick_place --local-dir models/act
cd robot && python run_policy.py dry --ckpt ../models/act
```

Normalization lives outside the policy in LeRobot 0.5.x. Load the bundled pre/post-processors with
`make_pre_post_processors(policy_cfg, pretrained_path=...)`, or the actions come out normalized.

**Limitations:** this model is specific to one robot, camera placement, scene and camera colour
settings (two cameras have a fixed white balance). Expect to fine-tune on your own demonstrations.

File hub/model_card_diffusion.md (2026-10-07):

---
license: mit
library_name: lerobot
pipeline_tag: robotics
tags:
- LeRobot
- diffusion-policy
- imitation-learning
- delta-robot
- pick-and-place
- real-world
datasets:
- KirkHaskell/delta_robot_bolt_pick_place
---

# Diffusion Policy: delta robot bolt pick-and-place (100 demos, 50k steps), 10/10 on the real robot

A [Diffusion Policy](https://arxiv.org/abs/2303.04137) trained with LeRobot 0.5.0 on all 100
demonstrations of [`KirkHaskell/delta_robot_bolt_pick_place`](https://huggingface.co/datasets/KirkHaskell/delta_robot_bolt_pick_place).
It drives a home-built 3-DOF delta robot with an electromagnet gripper: it picks up a standing bolt
and drops it into a cup.

**Real-robot result: 10/10 successes** (95% Wilson CI 72–100%). It succeeded at all 5 bolt
positions, including one partly hidden by the cup and one outside the demonstrated area, and every
trial needed a single grab attempt. It was the best of the 24 models in the study, and subjectively
the most impressive. Full study: <https://github.com/KirkEHaskell/delta-robot-act-vs-diffusion>

## ⚠️ This is a modified Diffusion Policy: the joint-state input must be zeroed

LeRobot's default Diffusion Policy failed on this robot. Trained on leader–follower teleoperation
data, it learned to copy its own joint state instead of using the cameras, and it never left the
start pose. This model differs from the defaults in four ways:

| Setting | LeRobot default | This model |
|---|---|---|
| Vision backbone | ResNet-18 from scratch, GroupNorm | ResNet-18 ImageNet-pretrained, BatchNorm |
| Augmentation | none | random crop 216×288 |
| Observation frames | 2 | 1 |
| Joint state | used | **zeroed after normalization, in training and at inference** |
| Horizon / executed actions | 16 / 8 | 48 / 24 (1.6 s / 0.8 s at 30 Hz) |

The checkpoint's config cannot express "state blinded." The model still has an `observation.state`
input, but it was trained with that input set to zeros. **At inference, zero
`batch["observation.state"]` after the preprocessor and before `select_action`.** The repo's
`robot/run_policy.py` does this automatically: this folder contains a `BLIND_STATE` marker file
that the script detects.

```python
batch = preprocessor(obs)
batch["observation.state"] = torch.zeros_like(batch["observation.state"])
action = postprocessor(policy.select_action(batch))
```

| | |
|---|---|
| Inputs | 3 cameras (`side`, `top_right`, `top_left`, 240×320); the joint state is present but zeroed |
| Output | 4-D action: 3 absolute joint targets (deg) + magnet (on if > 0.5) |
| Training | 50k steps, cosine LR, batch 32, seed 1000, fp32, one RTX 3090 (~3 h), with `BLIND_STATE=1` via `training/lerobot_train_fixed.py` |
| Inference in the study | DDPM, all 100 denoising steps, RTX 3090: ~0.76 s per 24-action plan. The robot pauses while it plans |
| CPU | DDPM-100 takes ~18 s per plan. DDIM with 10 steps takes ~2 s and matched DDPM-100 within ~1° offline, but was not used for the scored trials |

## Use

```bash
hf download KirkHaskell/diffusion_delta_robot_bolt_pick_place --local-dir models/diffusion
cd robot && python run_policy.py dry --ckpt ../models/diffusion
```

**Limitations:** this model is specific to one robot, camera placement, scene and camera colour
settings (two cameras have a fixed white balance). It is not real-time without a GPU. Undertrained
versions of this configuration tend to stall rather than act.

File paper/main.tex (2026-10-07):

\documentclass[10pt,twocolumn,letterpaper]{article}

% ---------------------------------------------------------------- packages
\usepackage[T1]{fontenc}
\usepackage[utf8]{inputenc}
\usepackage{newtxtext,newtxmath}
\usepackage[margin=0.75in,columnsep=0.25in]{geometry}
\usepackage{graphicx}
\usepackage{booktabs}
\usepackage{multirow}
\usepackage{array}
\usepackage{xcolor}
\usepackage{enumitem}
\usepackage[font=small,labelfont=bf,skip=4pt]{caption}
\usepackage{subcaption}
\usepackage[numbers,sort&compress]{natbib}
\usepackage{microtype}
\usepackage[colorlinks=true,linkcolor=blue!50!black,citecolor=blue!50!black,urlcolor=blue!50!black]{hyperref}

\graphicspath{{figures/}}
\setlist{nosep,leftmargin=*}
\newcommand{\repo}{\url{https://github.com/KirkEHaskell/delta-robot-act-vs-diffusion}}
\newcommand{\hf}{\url{https://huggingface.co/KirkHaskell}}
\newcommand{\best}[1]{\textbf{#1}}

\title{\Large\bfseries ACT vs.\ Diffusion Policy on a Home-Built Delta Robot:\\
Data and Training-Length Scaling for Real-World Pick-and-Place}
\author{Kirk Haskell\thanks{Independent project, carried out outside of coursework and not
supported or endorsed by Tufts University.}\\[1pt]
\small Tufts University\\[2pt]
\small Code, CAD, firmware, data and models: \repo}
\date{October 2026}

\begin{document}
\maketitle

% ================================================================ abstract
\begin{abstract}
We compare the two most widely used open-source imitation-learning policies, ACT and Diffusion
Policy, on a home-built 3-DOF delta robot with an electromagnet gripper performing a bolt
pick-and-place task. Both policies are trained on nested subsets of 10, 25, 50 and 100
teleoperated demonstrations for 5k, 20k and 50k optimizer steps, giving 24 models. Each model is
scored on 10 real-robot trials, for 240 trials in total. Out of the box, LeRobot's Diffusion
Policy never left its start pose. Input-ablation tests showed that it had learned to copy the
robot's own joint state, a shortcut that leader--follower teleoperation data makes nearly
optimal. An ImageNet-pretrained encoder, crop augmentation, a blinded joint-state input and a
1.6\,s action horizon fixed it. With these changes the best model, Diffusion Policy with 100
demonstrations and 50k steps, succeeded on \best{10/10} trials; the best ACT models reached 6/10.
Neither policy is usable with 10 demonstrations or 5k steps. ACT shows a clean data-scaling
trend at 50k steps ($0\rightarrow 20\rightarrow 50\rightarrow 60\%$, $p=0.0015$). Pooled over the
grid, the two policies are not significantly different (39/120 vs.\ 29/120, $p=0.20$). They fail
differently: ACT knocks the bolt over, Diffusion Policy stalls. We release the dataset, the trial
log, all code, CAD and firmware, and the two best checkpoints.
\end{abstract}

% ================================================================ 1
\section{Introduction}

Imitation learning from teleoperated demonstrations has become the default way to teach low-cost
robot arms manipulation skills. In open-source practice two policy classes dominate:
ACT~\cite{zhao2023act} and Diffusion Policy~\cite{chi2023diffusion}, both available in Hugging
Face's LeRobot library~\cite{cadene2024lerobot}. A practitioner adopting either one faces two
immediate questions: \emph{how many demonstrations are needed}, and \emph{how long to train}.

Published comparisons mostly report one data and compute setting on standard serial arms. This
study measures a full $4\times3$ grid of data and training length for both policies, on a
mechanically different robot, a parallel (delta) robot with a binary magnetic gripper, and scores
every model on the real robot under a fixed protocol.

\paragraph{Contributions.}
\begin{itemize}
  \item A controlled real-robot grid: 2 policies $\times$ 4 data sizes $\times$ 3 training lengths,
        240 scored trials, released with the raw trial log and the code that regenerates every
        number and figure.
  \item A documented failure of default Diffusion Policy on leader--follower data, an instance of
        the ``copycat'' problem~\cite{wen2020copycat}; an offline diagnostic that detects it in
        minutes, and a fix.
  \item An open 100-episode, 3-camera dataset in LeRobot v3.0 format for a delta-robot embodiment,
        which is rare in public robot-learning data.
  \item Open hardware (STL and URDF), firmware, and recording and evaluation software.
\end{itemize}

\begin{figure}[t]
  \centering
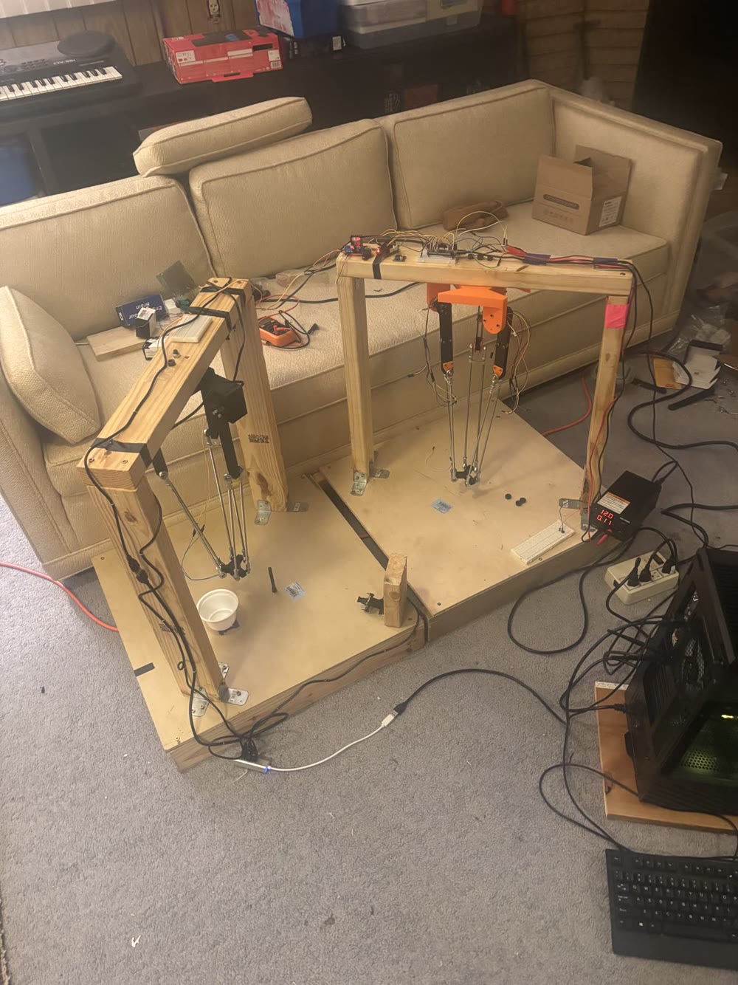
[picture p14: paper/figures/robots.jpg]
  
  \caption{The two robots. \textbf{Left:} the servo-driven follower that the policies control,
  with the cup and a standing bolt. \textbf{Right:} the hand-moved leader arm used for
  teleoperation, with a magnetic encoder at each shoulder joint.}
  \label{fig:robots}
\end{figure}

% ================================================================ 2
\section{Related Work}

\textbf{ACT}~\cite{zhao2023act} encodes camera images with a ResNet-18~\cite{he2016resnet} and
predicts chunks of future actions with a conditional-VAE transformer. \textbf{Diffusion
Policy}~\cite{chi2023diffusion} predicts an action sequence by iterative denoising
(DDPM~\cite{ho2020ddpm}; DDIM~\cite{song2021ddim} for faster sampling) conditioned on a short
observation history. Both are implemented in LeRobot~\cite{cadene2024lerobot}, which we use
throughout.

Behaviour cloning is known to latch onto spurious, easily predicted signals. Causal
confusion~\cite{dehaan2019causal} and the copycat problem~\cite{wen2020copycat} describe policies
that infer the next action from their own previous actions or state history instead of from the
task-relevant observation, a form of shortcut learning~\cite{geirhos2020shortcut}. We observe
this effect concretely on real hardware with an off-the-shelf implementation, and show how a
specific property of leader--follower data triggers it.

% ================================================================ 3
\section{System}

\paragraph{Robot.} A 3-DOF delta robot. Three printed upper arms are driven by Feetech STS3215
serial-bus servos; steel parallelogram rods with ball joints carry the end effector. The gripper
is an electromagnet ($\sim$12\,V) switched through an H-bridge, which lifts a standing steel bolt.
A Teensy~4.1 drives the servo bus at 1\,Mbit/s. Joint commands are absolute angles in degrees,
clamped to $[30^\circ, 110^\circ]$.

\paragraph{Teleoperation.} Demonstrations are collected leader--follower
(Fig.~\ref{fig:robots}): a second, passive delta arm carries an AS5600 magnetic encoder on each
shoulder, and the Teensy drives the follower servos to the leader's angles in real time. A push
button switches the magnet. The Teensy streams leader angles, follower angles and magnet state at
60\,Hz; the recorder samples at 30\,Hz.

\paragraph{Cameras.} Three Innomaker U20CAM-720P USB cameras (\texttt{side}, \texttt{top\_right},
\texttt{top\_left}, Fig.~\ref{fig:cams}) are captured at $320\times240$, 30\,fps. Three
uncompressed streams saturate a single USB hub, so capture forces MJPG through PyAV, and cameras
are addressed by physical USB port rather than OS index. In all recorded data the \texttt{side}
and \texttt{top\_right} cameras have a constant yellow-green cast. Their auto white balance was
off (4600\,K) and exposure fixed at $2^{-6}$\,s, a setting left behind by an earlier script and
persisted by the Windows driver. For evaluation on Linux the same settings were reproduced through
V4L2 controls and verified against the training video's luma and chroma statistics.

\begin{figure}[t]
  \centering
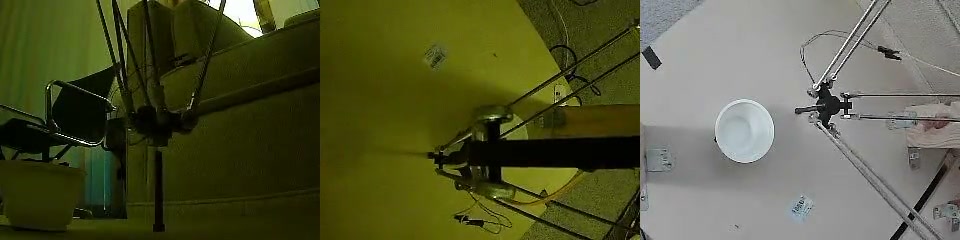
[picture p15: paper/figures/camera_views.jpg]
  
  \caption{The policy's input: one frame of demonstration 42 from the \texttt{side},
  \texttt{top\_right} and \texttt{top\_left} cameras ($320\times240$ each). Note the colour cast
  on the first two, constant across the dataset.}
  \label{fig:cams}
\end{figure}

% ================================================================ 4
\section{Dataset}

The dataset contains 100 demonstrations (33{,}200 frames at 30\,Hz, 8.1--17.3\,s each, median
10.7\,s), recorded by one operator on one day in ten sessions of ten. The observation is the
follower's three joint angles plus three RGB images; the action is the leader's three joint
angles plus the magnet command (Table~\ref{tab:dataset}).

\begin{table}[t]
  \centering\small
  \caption{Dataset summary (LeRobot v3.0, AV1 video, $\sim$600\,MB).}
  \label{tab:dataset}
  \begin{tabular}{@{}l>{\raggedright\arraybackslash}p{0.66\columnwidth}@{}}
    \toprule
    Episodes / frames & 100 / 33{,}200 at 30\,Hz \\
    Observation & 3 follower joint angles (deg); 3 RGB images $240\times320$ \\
    Action & 3 leader joint angles (deg) + magnet $\{0,1\}$ \\
    Task string & ``pick up the bolt and drop it in the bucket'' \\
    Grasps & exactly one magnet press in 99/100 episodes \\
    Start pose & $(91.7, 93.2, 90.8)^\circ$, s.d.\ $\approx3.5^\circ$ per joint \\
    \bottomrule
  \end{tabular}
\end{table}

Two properties matter for learning. First, every episode opens with $\sim$1.2\,s of stillness
(median 1.23\,s) and pauses $\sim$0.33\,s after the grasp. Second, because the action is the
leader's angle and the state is the follower's, the action is always within a fraction of a
degree of the next observed state. Section~\ref{sec:copycat} shows why the second property matters.

\paragraph{Subsets.} Training subsets are nested and seeded: the episodes are shuffled with a
fixed seed and the first $N$ are taken, so $\mathcal{D}_{10}\subset\mathcal{D}_{25}\subset
\mathcal{D}_{50}\subset\mathcal{D}_{100}$ (3{,}219 / 8{,}380 / 16{,}326 / 33{,}200 frames).

% ================================================================ 5
\section{Training}

All models use LeRobot 0.5.0, PyTorch 2.6 in fp32, batch size 32, seed 1000 and a single RTX 3090.
Batch size 32 was the largest at which Diffusion Policy fits in 24\,GB. Passes over the data range
from 5 epochs (100 demos, 5k steps) to 497 (10 demos, 50k steps).

\paragraph{ACT.} LeRobot defaults: ImageNet-pretrained ResNet-18, one observation frame, chunk
size 100 with all 100 actions executed before re-planning, VAE with KL weight 10, and a constant
learning rate of $10^{-5}$. Because the learning rate is constant, one 50k-step run per data size
supplies the 5k and 20k cells as intermediate checkpoints.

\paragraph{Diffusion Policy.} The cosine learning-rate schedule depends on the total number of
steps, so each of the 12 cells is a separate run. The LeRobot defaults (``v1'') did not work on
the robot (Section~\ref{sec:copycat}). All scored Diffusion results use the ``v2'' configuration
in Table~\ref{tab:v2}; everything else (subsets, batch size, seed, schedule) matches v1.

\begin{table}[t]
  \centering\small
  \caption{Diffusion Policy: LeRobot defaults (v1) vs.\ the configuration used for all scored
  results (v2). The 48/24 horizon reproduces the original paper's 1.6\,s\,/\,0.8\,s at 30\,Hz.}
  \label{tab:v2}
  \footnotesize\setlength{\tabcolsep}{4pt}
  \begin{tabular}{@{}lll@{}}
    \toprule
    & v1 (default) & v2 \\
    \midrule
    Vision encoder & ResNet-18, scratch, GroupNorm & ImageNet, BatchNorm \\
    Augmentation & none & random crop $216\times288$ \\
    Observation frames & 2 & 1 \\
    Joint state & used & \textbf{zeroed} (train + test) \\
    Horizon / executed & 16 / 8 (0.53\,s) & 48 / 24 (1.6\,s) \\
    \bottomrule
  \end{tabular}
\end{table}

\paragraph{Training loss.} All 28 grid runs completed and their loss decreased throughout
(Fig.~\ref{fig:loss}). For both policies, \emph{fewer} demonstrations gave \emph{lower} final
loss (memorization), the opposite of the robot-success ordering. ACT's loss (L1 + KL) and
Diffusion's (noise-prediction MSE) are not comparable with each other.

\paragraph{A LeRobot 0.5.0 bug.} With episode subsets, Diffusion's episode-aware sampler yields
absolute frame indices into a dataset indexed relative to the subset. Training then crashes or
silently reads the wrong frames. A small wrapper that remaps the indices (released) was used for
every run.

\begin{figure*}[t]
  \centering
  
  \caption{Training loss of the 50k-step runs from step 500 onward (lightly smoothed, log--log axes). Fewer
  demonstrations always reach a lower loss, while robot success moves the other way
  (Fig.~\ref{fig:grid}). Losses are not comparable across the two panels.}
  \label{fig:loss}
\end{figure*}

% ================================================================ 6
\section{The Copycat Failure of Default Diffusion Policy}
\label{sec:copycat}

\paragraph{Symptom.} On the real robot every v1 Diffusion checkpoint held still at its start pose.
Changing the inference setup did not help: GPU or CPU, DDPM-100 or DDIM-10, fixed initial noise,
longer executed chunks, or a scripted ``kick-start'' lift, after which the arm stopped again. ACT
on the same rig moved normally.

\paragraph{Diagnosis.} We probed checkpoints offline on training episodes:
\begin{itemize}
  \item \emph{Teacher-forced replay} looked perfect ($\sim$0.4$^\circ$ error), so it reveals nothing.
  \item \emph{Images only} (images play the demonstration, joint state frozen at frame 0): ACT
        reproduced 92\% of the demonstrated motion range, v1 Diffusion only 37\%.
  \item \emph{State only} (images frozen, state moving): v1 Diffusion followed the state.
  \item \emph{Still start} (robot at rest, first camera frame): v1 Diffusion (50 demos, 50k steps)
        commanded $<1^\circ$ of motion, and longer training made this worse.
\end{itemize}
The policy had learned ``next action $\approx$ current joint state (+ velocity from the two
observation frames)''. With leader--follower data this is a near-perfect predictor over a short
horizon, and a still robot then predicts a still robot. The v1 defaults favour this shortcut:
a vision encoder trained from scratch, no augmentation, two state frames that expose velocity,
and a 0.53\,s horizon. ACT's pretrained encoder, single frame and 3.3\,s chunks push it towards
the images.

\paragraph{Fix.} Figure~\ref{fig:copycat} shows the pilot variants (50 demos, 5k steps).
Pretrained vision with crop augmentation barely helped (42\%). \emph{Blinding the joint state} was
decisive (96\%): the policy moved and grasped, but jittered and hesitated. Extending the horizon
to 1.6\,s removed most of the jitter, and this v2 pilot completed a pick-and-place. Fully trained
v2 models were 99--100\% image-driven by this measure.

\begin{figure}[t]
  \centering
  
  \caption{Images-only ablation: the share of the demonstrated motion range a policy reproduces
  when the joint state is frozen and only the images move. Diffusion bars are cumulative changes
  to the LeRobot defaults (50 demos, 5k steps).}
  \label{fig:copycat}
\end{figure}

% ================================================================ 7
\section{Robot Evaluation}

\paragraph{Protocol.} Five bolt positions are marked on the table. P1--P3 lie inside the
demonstrated region. P4 lies inside it but is partly hidden by the cup and awkward to reach. P5
lies outside the demonstrated region but is easy to reach. Each model receives two trials per
position (10 per model). The cup position, lighting and camera setup are fixed, and models are
tested in a seeded random order. Each trial starts from the dataset's mean start pose and runs at
30\,Hz until the operator stops it or 900 actions (30\,s of motion) elapse. Success means the
bolt ends in the cup. The operator also logged whether the bolt was picked up, the number of
grasp attempts and a failure mode. Unsafe stops, where the operator halts erratic motion, count
as failures.

\paragraph{Inference.} ACT ran on a laptop CPU (Ryzen AI 9 HX 370, 0.1--0.37\,s per 100-action
chunk, 29.3--29.9\,Hz measured). Diffusion v2 ran on the RTX 3090 with DDPM-100 as trained,
taking $\sim$0.76\,s per 24-action plan; the robot pauses while it plans, which is acceptable for
this quasi-static task. On the laptop CPU, Diffusion would take $\sim$18\,s per plan.

\begin{table}[t]
  \centering\small
  \setlength{\tabcolsep}{4.5pt}
  \caption{Successes out of 10 trials per model. Superscripts: trials stopped as unsafe.}
  \label{tab:grid}
  \begin{tabular}{@{}r ccc c ccc@{}}
    \toprule
    & \multicolumn{3}{c}{ACT} && \multicolumn{3}{c}{Diffusion Policy (v2)} \\
    \cmidrule{2-4}\cmidrule{6-8}
    Demos & 5k & 20k & 50k && 5k & 20k & 50k \\
    \midrule
    10  & $0^{10}$ & $0^{2}$ & 0        && $0^{10}$ & $0^{2}$ & 2 \\
    25  & $0^{2}$  & 6       & 2        && $1^{2}$  & \best{8} & 5 \\
    50  & $1^{4}$  & $6^{1}$ & 5        && $2^{2}$  & 4       & 1 \\
    100 & $0^{10}$ & 3       & \best{6} && $0^{2}$  & 6       & \best{10} \\
    \midrule
    Total & \multicolumn{3}{c}{29/120 (24\%)} && \multicolumn{3}{c}{39/120 (33\%)} \\
    \bottomrule
  \end{tabular}
\end{table}

\begin{figure*}[t]
  \centering
  
  \caption{Real-robot success for every model (10 trials each).}
  \label{fig:grid}
\end{figure*}

\begin{figure*}[t]
  \centering
  
  \caption{Success rate against the number of demonstrations, one line per training length.
  Error bars are 95\% Wilson intervals~\cite{wilson1927} ($n=10$); points are dodged
  horizontally for legibility.}
  \label{fig:demos}
\end{figure*}

\subsection{Results}

Table~\ref{tab:grid} and Fig.~\ref{fig:grid} give the full grid; Figs.~\ref{fig:demos}
and~\ref{fig:steps} show the two scaling axes. Table~\ref{tab:stats} lists the statistical
tests, with trends tested by Cochran--Armitage~\cite{armitage1955} on $\log_2$ of the varied
quantity and policy comparisons by Fisher's exact test.

\begin{table}[t]
  \centering\small
  \setlength{\tabcolsep}{3pt}
  \caption{Statistical tests (two-sided).}
  \label{tab:stats}
  \begin{tabular}{@{}lll@{}}
    \toprule
    Comparison & Successes & $p$ \\
    \midrule
    ACT, demos trend @ 50k & 0, 2, 5, 6 & 0.0015 \\
    ACT, steps trend @ 100 demos & 0, 3, 6 & 0.004 \\
    Diffusion, steps trend @ 100 demos & 0, 6, 10 & $<10^{-4}$ \\
    Diffusion, demos trend @ 50k & 2, 5, 1, 10 & 0.005$^\dagger$ \\
    ACT vs.\ Diffusion, pooled (12 cells) & 29 vs.\ 39 /120 & 0.20 \\
    ACT vs.\ Diffusion, 100 demos @ 50k & 6 vs.\ 10 /10 & 0.087 \\
    \bottomrule
    \multicolumn{3}{@{}l}{\footnotesize $^\dagger$ significant but not monotone.}
  \end{tabular}
\end{table}

\begin{figure*}[t]
  \centering
  
  \caption{Success rate against training length, one line per data size.}
  \label{fig:steps}
\end{figure*}

\paragraph{Clustering caveat.} The two trials at the same position agreed in 88\% of pairs, so
each model's 10 trials carry roughly the information of 5 independent outcomes. All $p$-values
should therefore be read as optimistic, and single cells as noisy: a 6/10 cell has a 95\% interval
of 31--83\%.

\paragraph{Failure modes.} The policies fail in characteristically different ways
(Fig.~\ref{fig:outcomes}). ACT fails \emph{aggressively}: it drives to the bolt and grasps
imprecisely, knocking the standing bolt over (39 trials). Undertrained ACT at 5k steps was erratic
enough to be stopped on every trial at both 10 and 100 demonstrations. Diffusion v2 fails
\emph{hesitantly}: it hovers or freezes (52 stalls), most often before the grasp. This matches
the still segments in the demonstrations. With the state blinded, a still camera view is
ambiguous between ``about to move'' and ``waiting'', and an undertrained model can stay in the
waiting mode.

\begin{figure}[t]
  \centering
  
  \caption{Outcome of all 120 trials per policy.}
  \label{fig:outcomes}
\end{figure}

\paragraph{Bolt position.} P4, the occluded position, was the hardest (Fig.~\ref{fig:position}):
ACT succeeded once in 24 trials and Diffusion 7 times, and P4 accounted for 21 of the 47 unsafe
stops. The out-of-distribution position P5 was \emph{not} the hardest: both 100-demo ACT models
and the best Diffusion model went 2/2 there. Unexpectedly, both 100-demo ACT models failed at P1,
the most heavily demonstrated position, while the 50-demo ACT models succeeded there. One
untested explanation is that ACT's latent is fixed to its mean at test time, so many slightly
different P1 grasps average into one a few millimetres off, and the magnet needs near-contact.

\begin{figure}[t]
  \centering
  
  \caption{Success by bolt position, pooled over each policy's 12 models (numbers: successes
  out of 24).}
  \label{fig:position}
\end{figure}

\paragraph{Best model.} Diffusion v2 with 100 demonstrations and 50k steps succeeded on all 10
trials, at every position including the occluded P4 and out-of-distribution P5, each with a single
grasp attempt (Fig.~\ref{fig:filmstrip}). Subjectively it was also the most convincing policy in
the study. Three ACT models reached 6/10. We release the 100-demo, 50k-step ACT as the reference
ACT model because it runs in real time on a laptop CPU and was never stopped as unsafe.

\begin{figure*}[t]
  \centering
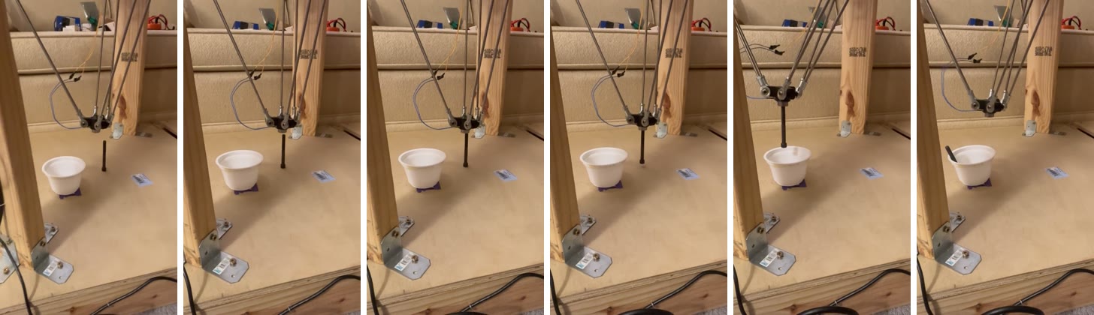
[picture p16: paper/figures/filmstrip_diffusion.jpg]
  
  \caption{The best model (Diffusion Policy v2, 100 demonstrations, 50k steps) completing the task
  autonomously: approach, magnetic grasp, transport, and release into the cup (frames
  $\sim$2\,s apart).}
  \label{fig:filmstrip}
\end{figure*}

% ================================================================ 8
\section{Discussion}

\paragraph{Training length is the first gate.} At 5k steps neither policy is usable (4/80 trials
combined), whatever the data size; for 100 demonstrations this is only 5 epochs. Given enough
steps, more data helps both policies, most clearly at 50k.

\paragraph{Possible overtraining at small and medium data.} At 25 demonstrations both policies did
better at 20k than at 50k steps (ACT $6\rightarrow2$, Diffusion $8\rightarrow5$), and Diffusion at
50 demonstrations fell from 4 to 1. No single drop is significant at $n=10$, but the direction
repeats three times while training loss keeps falling, and at 100 demonstrations longer training
only helped. Scaling training steps with dataset size, rather than training small datasets
longer, is a reasonable hypothesis that this data cannot confirm.

\paragraph{Policy choice is a trade-off.} Modified Diffusion Policy produced the single best model
and handled the occluded position far better. ACT was competitive in the middle of the grid,
runs in real time on a laptop CPU, and needed no changes. The pooled difference is within noise.

\paragraph{Proprioception and leader--follower data.} The same data trained ACT without trouble,
but ACT's loss of precision at P1 with 100 demonstrations hints that it may also lean on state.
A proprioception ablation for ACT is the natural next experiment. Diffusion's stalling probably
comes from the still segments in the data, so trimming them is a likely remedy. For dataset
builders the lesson is that leader--follower data invites state-copying, and that low loss or good
teacher-forced replay does not rule it out, whereas an images-only ablation does.

% ================================================================ 9
\section{Limitations}

\begin{itemize}
  \item \textbf{Unequal conditions.} ACT was evaluated on a Windows laptop CPU on 2--3 October and
        Diffusion on a Linux GPU desktop on 5 October. The random order held within each policy,
        not across them, so drift between days could align with policy.
  \item \textbf{Diffusion v2 is not stock Diffusion Policy}: it has no proprioception, pretrained
        vision, crop augmentation and a longer horizon, whereas ACT used defaults. Stock v1 was not
        formally scored; it never completed a pick in informal testing.
  \item \textbf{Small samples}: 10 trials per model, 5 positions, strong within-position clustering,
        and one training seed per cell.
  \item \textbf{Non-blind scoring}: the operator knew which model was running.
  \item \textbf{Hardware events during ACT testing}: a printed upper arm was replaced with an
        identical part; a faulty leader-encoder cable was unplugged; the firmware was patched to
        skip the missing encoders in autonomous mode; a loose magnet wire was fixed. All scored ACT
        runs logged $\sim$29.5\,Hz control.
  \item \textbf{Scene drift} between recording and testing was corrected by restoring the scene
        against the demonstration videos.
\end{itemize}

% ================================================================ 10
\section{Conclusion}

On a home-built delta robot doing pick-and-place, both ACT and Diffusion Policy need roughly
$\geq$25 demonstrations and $\geq$20k training steps before they work at all, and more data pays
off most with long training. The two policies fail in characteristically different ways. Default
Diffusion Policy can silently learn to ignore its cameras on leader--follower data; a simple
ablation exposes this and blinding proprioception fixes it, after which Diffusion Policy trained on
100 demonstrations for 50k steps solved the task in 10 of 10 trials. Future work: more trials and
seeds with blind scoring, a proprioception ablation for ACT, trimming still frames from the
demonstrations, temporal ensembling for ACT, and faster Diffusion sampling for real-time control.

\paragraph{Release.} Dataset, models: \hf. Code, CAD, firmware, trial log and figure scripts:
\repo.

\small
\bibliographystyle{unsrtnat}
\bibliography{references}

\end{document}

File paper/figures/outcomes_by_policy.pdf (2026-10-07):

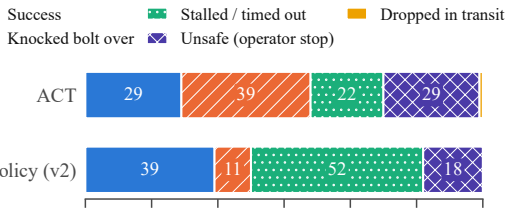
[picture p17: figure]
ACT; Success Knocked bolt over; Stalled / timed out Unsafe (operator stop); Dropped in transit

0 | 20 | 40 | 60 | 80 | 100 | 120

### Trials (of 120 per policy)

### Diffusion Policy (v2)

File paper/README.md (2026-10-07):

# Paper (LaTeX)

`main.tex` + `references.bib` + `figures/`. Compiles with pdfLaTeX on Overleaf (New Project → Upload
Project → select `paper_overleaf.zip`, or upload this folder's files).

Figures are generated from the data by `python analysis/make_paper_figures.py` (run `python
analysis/analyze_results.py` first). Re-run both if the trial log changes, then re-upload `figures/`.

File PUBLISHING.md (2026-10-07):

# Publishing checklist (first time on GitHub + Hugging Face)

This file is for the author. Delete it before publishing, or keep it as notes.

## 0. Fill in names

Every `KirkHaskell`, `KirkEHaskell` and `Kirk Haskell` in the repo needs to be replaced with your
Hugging Face username, GitHub username and name.

## 1. Hugging Face: dataset + two models

1. Create an account at <https://huggingface.co/join>.
2. Create an access token with **write** permission at <https://huggingface.co/settings/tokens>.
3. Log in from this laptop. Don't upgrade huggingface_hub past 1.x; LeRobot 0.5 needs it below 2.
   ```bash
   hf auth login
   ```
   Paste the token when it asks (nothing shows while you paste). Answer `n` to "Add token as git credential?".
4. From this folder (`delta-robot-imitation`), stage all three uploads:
   ```bash
   python hub/prepare_upload.py --dataset ../bolt_pickplace/datasets/MasterDataset --act ../bolt_pickplace/TRAINEDMODELSFROMMASTERDATASET/checkpoints/act_n100_s50k_050000 --diffusion ../050000/pretrained_model
   ```
5. Run the three `hf upload ...` commands the script prints, then its `create_tag` command.
   The tag is what lets `LeRobotDataset("KirkHaskell/delta_robot_bolt_pick_place")` download the dataset.
6. Open the three pages on huggingface.co and check that they render.

## 2. GitHub: the code repo

1. Create an account at <https://github.com/signup>.
2. Create a **new, empty** repository named `delta-robot-act-vs-diffusion`. Make it public, and
   don't add a README, license or .gitignore (this folder already has them).
3. From this folder (`delta-robot-imitation`), run:
   ```bash
   git init -b main
   ```
   ```bash
   git add .
   ```
   ```bash
   git commit -m "Initial release: ACT vs Diffusion Policy on a delta robot"
   ```
   ```bash
   git remote add origin https://github.com/KirkEHaskell/delta-robot-act-vs-diffusion.git
   ```
   ```bash
   git push -u origin main
   ```
   The first push opens a browser window to sign in to GitHub.
4. On the repo page, click the gear next to **About** and set:
   - **Description:** "ACT vs Diffusion Policy on a home-built delta robot: 240 real-world trials,
     open dataset, CAD, firmware and models (LeRobot)"
   - **Topics:** `robotics` `imitation-learning` `lerobot` `diffusion-policy` `act` `robot-learning`
     `delta-robot` `teleoperation` `pick-and-place` `open-hardware` `pytorch` `real-robot`
5. Settings → General → Social preview: upload `media/photos/leader_and_follower.jpg` or `media/robot_carrying_bolt.jpg` (the image shown when the link is shared).
6. Optional: drag `media/diffusion_best_n100_s50k.mp4` into a README edit on github.com. GitHub turns it into an
   inline video player, which looks better than the GIF.

## 3. Getting it seen

- In the Hugging Face dataset page, the `LeRobot` tag puts it in the LeRobot community datasets list
  (<https://huggingface.co/datasets?other=LeRobot>). That list is where people assembling pretraining
  mixtures look.
- Share it in the LeRobot Discord (#show-and-tell) and on X/LinkedIn with
  `media/diffusion_best_n100_s50k.mp4` and the one-line result: "Default Diffusion Policy learned to
  ignore its cameras on leader–follower data. Blinding proprioception fixed it, and the best model
  went 10/10 on the real robot."
- Link the GitHub repo from the Hugging Face cards (already done) and vice versa (already done).

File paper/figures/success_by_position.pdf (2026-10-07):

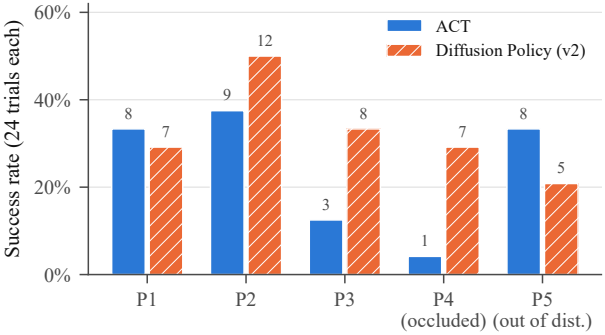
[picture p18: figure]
(occluded); P5 (out of dist.); Success rate (24 trials each); ACT Diffusion Policy (v2)

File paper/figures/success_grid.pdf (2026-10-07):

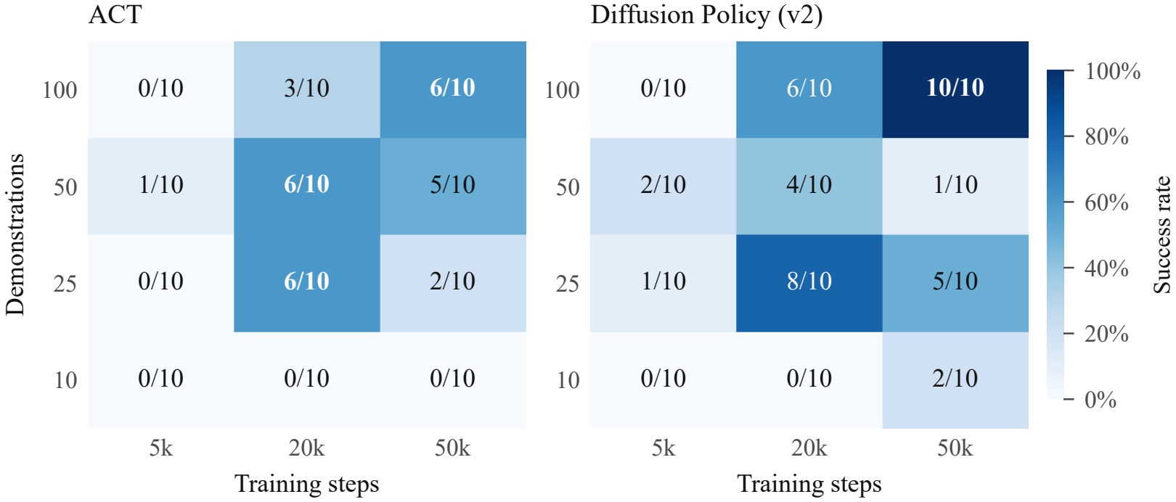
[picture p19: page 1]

5k | 20k | 50k
| Training steps

10

25

50

100

Demonstrations

0/10 | 0/10 | 0/10
0/10 | 6/10 | 2/10
1/10 | 6/10 | 5/10
0/10 | 3/10 | 6/10

ACT

5k | 20k | 50k
| Training steps

10

25

50

100

0/10 | 0/10 | 2/10
1/10 | 8/10 | 5/10
2/10 | 4/10 | 1/10
0/10 | 6/10 | 10/10

Diffusion Policy (v2)

0%

20%

40%

60%

80%

100%

Success rate

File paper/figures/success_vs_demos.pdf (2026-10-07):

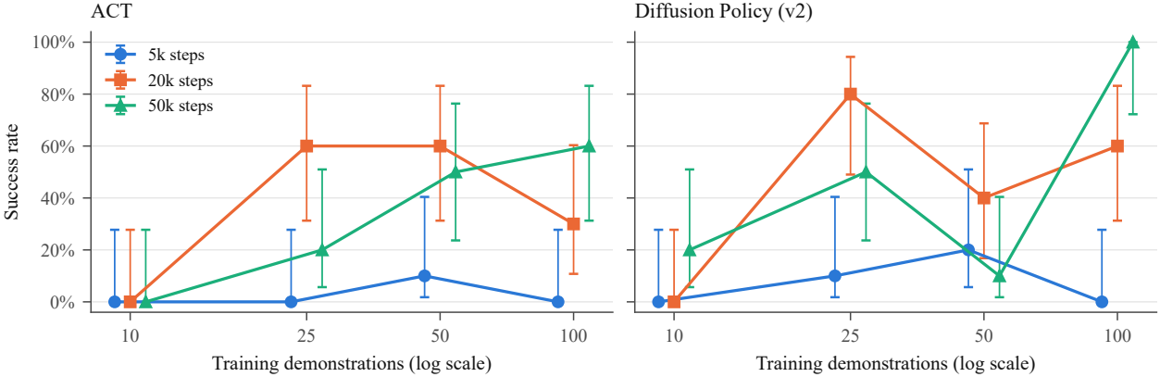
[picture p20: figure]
Training demonstrations (log scale); Success rate; ACT; 5k steps 20k steps 50k steps; Diffusion Policy (v2)

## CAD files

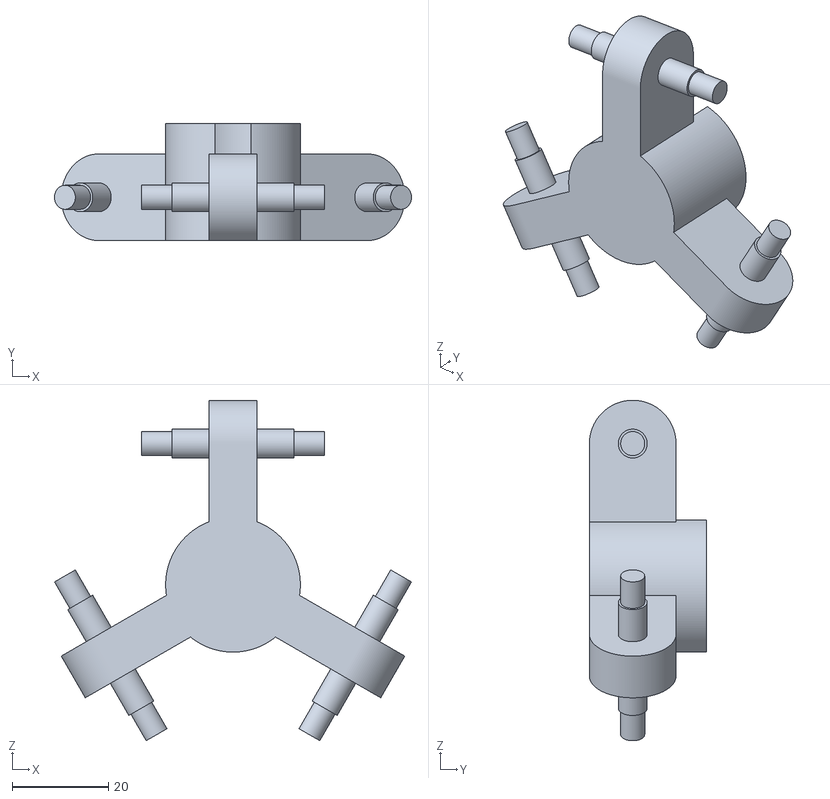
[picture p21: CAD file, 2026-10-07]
hardware/stl/end_effector_electromagnet.stl
74.2 x 24.4 x 70.7

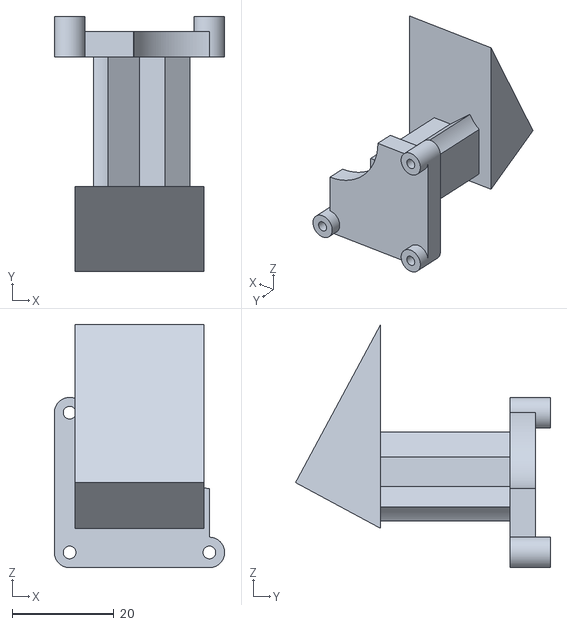
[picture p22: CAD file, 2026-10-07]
hardware/stl/camera_holder.stl
33.5 x 50.2 x 47.9

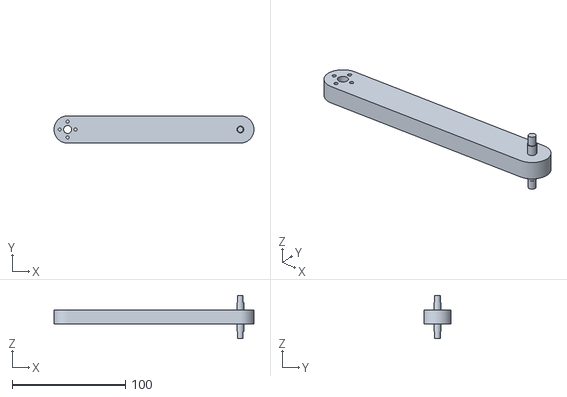
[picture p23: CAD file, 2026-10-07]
hardware/stl/upper_arm_6in_12mm.stl
176.4 x 24.0 x 38.1

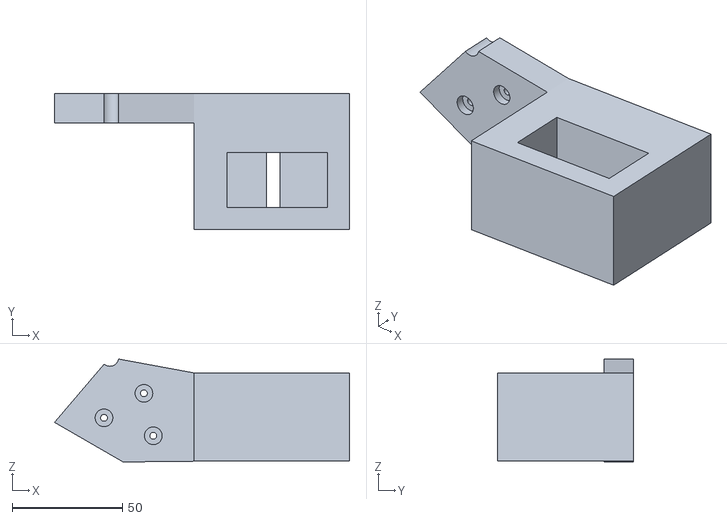
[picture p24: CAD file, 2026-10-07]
hardware/stl/base_part2.stl
133.5 x 61.7 x 46.6

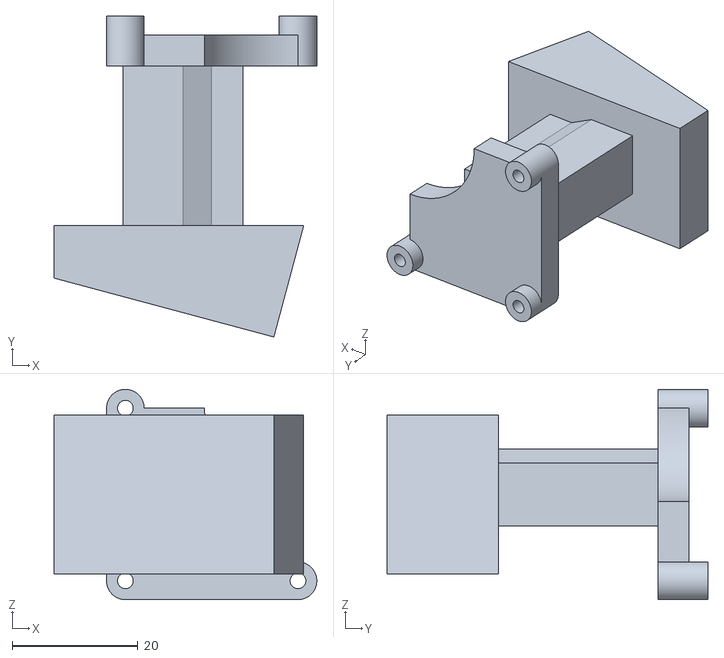
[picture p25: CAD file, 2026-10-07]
hardware/stl/camera_holder_base_mount.stl
41.8 x 51.1 x 33.5

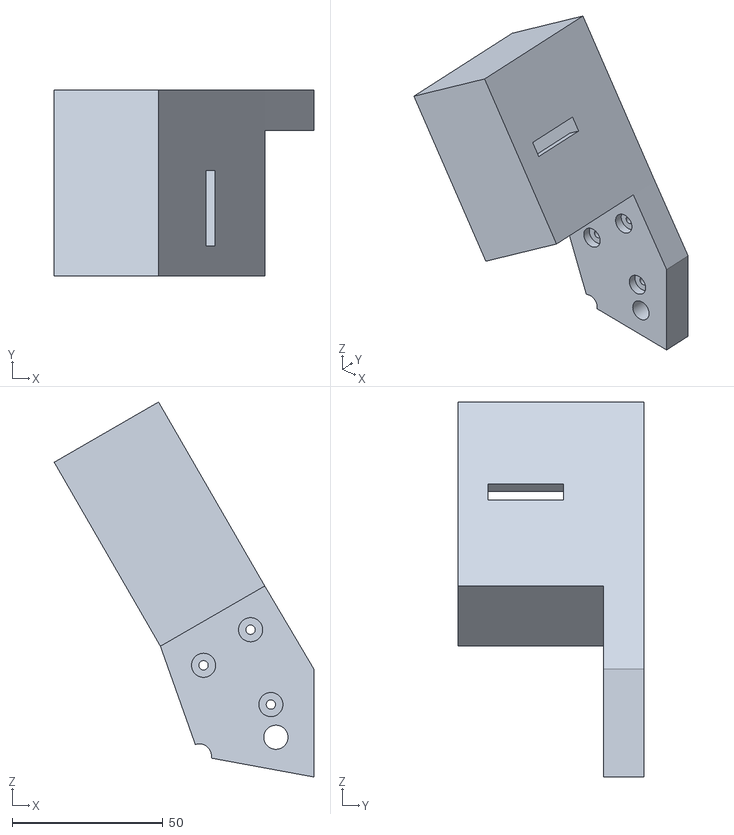
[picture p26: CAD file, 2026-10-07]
hardware/stl/base_part1.stl
86.2 x 61.7 x 124.5

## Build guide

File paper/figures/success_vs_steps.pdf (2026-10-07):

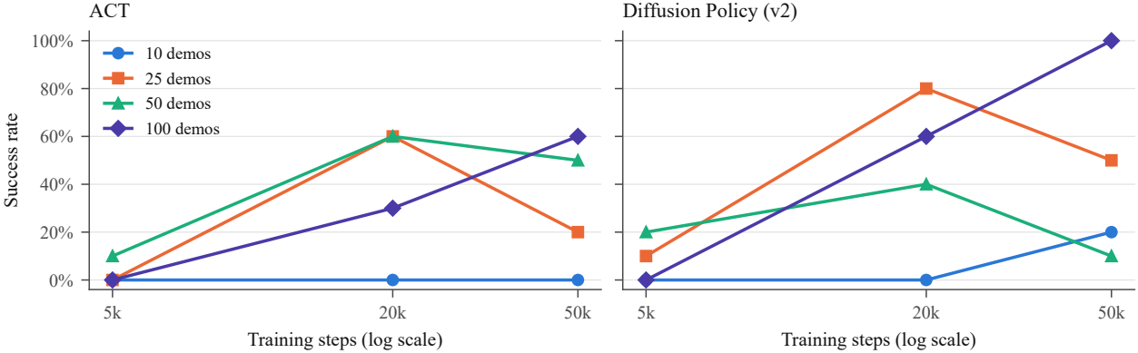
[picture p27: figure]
Training steps (log scale); Success rate; ACT; 10 demos 25 demos 50 demos 100 demos; Diffusion Policy (v2)

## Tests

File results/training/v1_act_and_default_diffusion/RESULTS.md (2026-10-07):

# Scaling-study results (training side)
_Generated 2026-10-02 11:37. All runs: batch 32, seed 1000, fp32, lerobot 0.5.0, torch 2.6.0, policy defaults, pyav decoding._

Copy a checkpoint's `pretrained_model/` folder to the laptop for inference. Paths are relative to `outputs/train/`.

**ACT cells** come from one 50k run per data size (ACT's LR is constant, so its 5k/20k checkpoints are exactly what a separate 5k/20k run would produce). **Diffusion cells** are separate runs (its cosine LR schedule depends on total steps).

**Loss values are not comparable across policies** (ACT: L1 + KL; Diffusion: noise-prediction MSE), and training loss is not task success - judge the grid by robot success rate.

| policy | episodes | steps | status | loss at end of cell | checkpoints (`<run>/checkpoints/<step>/pretrained_model`) |
|---|---|---|---|---|---|
| act | 50 | 5k | done | 0.1914 | `act_n50_s50k/checkpoints/` 000500, 001000, 001500, 002000, 002500, 003000, 003500, 004000, 004500, 005000 |
| act | 50 | 20k | done | 0.0662 | `act_n50_s50k/checkpoints/` 002000, 004000, 006000, 008000, 010000, 012000, 014000, 016000, 018000, 020000 |
| act | 50 | 50k | done | 0.0405 | `act_n50_s50k/checkpoints/` 005000, 010000, 015000, 020000, 025000, 030000, 035000, 040000, 045000, 050000 |
| act | 10 | 5k | done | 0.1419 | `act_n10_s50k/checkpoints/` 000500, 001000, 001500, 002000, 002500, 003000, 003500, 004000, 004500, 005000 |
| act | 10 | 20k | done | 0.0444 | `act_n10_s50k/checkpoints/` 002000, 004000, 006000, 008000, 010000, 012000, 014000, 016000, 018000, 020000 |
| act | 10 | 50k | done | 0.0253 | `act_n10_s50k/checkpoints/` 005000, 010000, 015000, 020000, 025000, 030000, 035000, 040000, 045000, 050000 |
| act | 25 | 5k | done | 0.1678 | `act_n25_s50k/checkpoints/` 000500, 001000, 001500, 002000, 002500, 003000, 003500, 004000, 004500, 005000 |
| act | 25 | 20k | done | 0.0561 | `act_n25_s50k/checkpoints/` 002000, 004000, 006000, 008000, 010000, 012000, 014000, 016000, 018000, 020000 |
| act | 25 | 50k | done | 0.0329 | `act_n25_s50k/checkpoints/` 005000, 010000, 015000, 020000, 025000, 030000, 035000, 040000, 045000, 050000 |
| act | 100 | 5k | done | 0.2162 | `act_n100_s50k/checkpoints/` 000500, 001000, 001500, 002000, 002500, 003000, 003500, 004000, 004500, 005000 |
| act | 100 | 20k | done | 0.0812 | `act_n100_s50k/checkpoints/` 002000, 004000, 006000, 008000, 010000, 012000, 014000, 016000, 018000, 020000 |
| act | 100 | 50k | done | 0.0487 | `act_n100_s50k/checkpoints/` 005000, 010000, 015000, 020000, 025000, 030000, 035000, 040000, 045000, 050000 |
| diffusion | 10 | 5k | done | 0.0099 | `diffusion_n10_s5k/checkpoints/` 000500, 001000, 001500, 002000, 002500, 003000, 003500, 004000, 004500, 005000 |
| diffusion | 25 | 5k | done | 0.0127 | `diffusion_n25_s5k/checkpoints/` 000500, 001000, 001500, 002000, 002500, 003000, 003500, 004000, 004500, 005000 |
| diffusion | 50 | 5k | done | 0.0147 | `diffusion_n50_s5k/checkpoints/` 000500, 001000, 001500, 002000, 002500, 003000, 003500, 004000, 004500, 005000 |
| diffusion | 100 | 5k | done | 0.0156 | `diffusion_n100_s5k/checkpoints/` 000500, 001000, 001500, 002000, 002500, 003000, 003500, 004000, 004500, 005000 |
| diffusion | 10 | 20k | done | 0.0029 | `diffusion_n10_s20k/checkpoints/` 002000, 004000, 006000, 008000, 010000, 012000, 014000, 016000, 018000, 020000 |
| diffusion | 25 | 20k | done | 0.0048 | `diffusion_n25_s20k/checkpoints/` 002000, 004000, 006000, 008000, 010000, 012000, 014000, 016000, 018000, 020000 |
| diffusion | 50 | 20k | done | 0.0068 | `diffusion_n50_s20k/checkpoints/` 002000, 004000, 006000, 008000, 010000, 012000, 014000, 016000, 018000, 020000 |
| diffusion | 100 | 20k | done | 0.0087 | `diffusion_n100_s20k/checkpoints/` 002000, 004000, 006000, 008000, 010000, 012000, 014000, 016000, 018000, 020000 |
| diffusion | 10 | 50k | done | 0.0011 | `diffusion_n10_s50k/checkpoints/` 005000, 010000, 015000, 020000, 025000, 030000, 035000, 040000, 045000, 050000 |
| diffusion | 25 | 50k | done | 0.0022 | `diffusion_n25_s50k/checkpoints/` 005000, 010000, 015000, 020000, 025000, 030000, 035000, 040000, 045000, 050000 |
| diffusion | 50 | 50k | done | 0.0037 | `diffusion_n50_s50k/checkpoints/` 005000, 010000, 015000, 020000, 025000, 030000, 035000, 040000, 045000, 050000 |
| diffusion | 100 | 50k | done | 0.0058 | `diffusion_n100_s50k/checkpoints/` 005000, 010000, 015000, 020000, 025000, 030000, 035000, 040000, 045000, 050000 |

## Runs

| run | wall time | step/s | loss start -> end |
|---|---|---|---|
| act_n50_s50k | 3.17 h | 4.38 | 2.560 -> 0.0405 |
| act_n10_s50k | 3.42 h | 4.06 | 2.533 -> 0.0253 |
| act_n25_s50k | 3.23 h | 4.30 | 2.547 -> 0.0329 |
| act_n100_s50k | 3.13 h | 4.44 | 2.552 -> 0.0487 |
| diffusion_n10_s5k | 0.45 h | 3.09 | 0.244 -> 0.0090 |
| diffusion_n25_s5k | 0.41 h | 3.35 | 0.241 -> 0.0120 |
| diffusion_n50_s5k | 0.40 h | 3.44 | 0.241 -> 0.0140 |
| diffusion_n100_s5k | 0.40 h | 3.50 | 0.243 -> 0.0150 |
| diffusion_n10_s20k | 1.71 h | 3.24 | 0.148 -> 0.0029 |
| diffusion_n25_s20k | 1.59 h | 3.49 | 0.146 -> 0.0048 |
| diffusion_n50_s20k | 1.56 h | 3.56 | 0.146 -> 0.0068 |
| diffusion_n100_s20k | 1.53 h | 3.63 | 0.147 -> 0.0087 |
| diffusion_n10_s50k | 4.25 h | 3.27 | 0.148 -> 0.0011 |
| diffusion_n25_s50k | 4.00 h | 3.48 | 0.146 -> 0.0022 |
| diffusion_n50_s50k | 3.85 h | 3.61 | 0.146 -> 0.0037 |
| diffusion_n100_s50k | 3.81 h | 3.64 | 0.147 -> 0.0058 |

## Plots

- `compare_act_by_data.png`
- `compare_diffusion_s5k_by_data.png`
- `compare_diffusion_s20k_by_data.png`
- `compare_diffusion_s50k_by_data.png`
- `compare_diffusion_n10_by_steps.png`
- `compare_diffusion_n25_by_steps.png`
- `compare_diffusion_n50_by_steps.png`
- `compare_diffusion_n100_by_steps.png`
- `act_n50_s50k_plot.png`
- `act_n10_s50k_plot.png`
- `act_n25_s50k_plot.png`
- `act_n100_s50k_plot.png`
- `diffusion_n10_s5k_plot.png`
- `diffusion_n25_s5k_plot.png`
- `diffusion_n50_s5k_plot.png`
- `diffusion_n100_s5k_plot.png`
- `diffusion_n10_s20k_plot.png`
- `diffusion_n25_s20k_plot.png`
- `diffusion_n50_s20k_plot.png`
- `diffusion_n100_s20k_plot.png`
- `diffusion_n10_s50k_plot.png`
- `diffusion_n25_s50k_plot.png`
- `diffusion_n50_s50k_plot.png`
- `diffusion_n100_s50k_plot.png`

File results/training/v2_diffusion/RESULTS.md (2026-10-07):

# Scaling-study results (training side)
_Generated 2026-10-05 19:49. All runs: batch 32, seed 1000, fp32, lerobot 0.5.0, torch 2.6.0, policy defaults, pyav decoding._

Copy a checkpoint's `pretrained_model/` folder to the laptop for inference. Paths are relative to `outputs/train/`.

**ACT cells** come from one 50k run per data size (ACT's LR is constant, so its 5k/20k checkpoints are exactly what a separate 5k/20k run would produce). **Diffusion cells** are separate runs (its cosine LR schedule depends on total steps).

**Loss values are not comparable across policies** (ACT: L1 + KL; Diffusion: noise-prediction MSE), and training loss is not task success - judge the grid by robot success rate.

| policy | episodes | steps | status | loss at end of cell | checkpoints (`<run>/checkpoints/<step>/pretrained_model`) |
|---|---|---|---|---|---|
| diffusion | 50 | 5k | done | 0.0134 | `diffusionnostateh48_n50_s5k/checkpoints/` 000500, 001000, 001500, 002000, 002500, 003000, 003500, 004000, 004500, 005000 |
| diffusion | 10 | 5k | done | 0.0088 | `diffusionnostateh48_n10_s5k/checkpoints/` 000500, 001000, 001500, 002000, 002500, 003000, 003500, 004000, 004500, 005000 |
| diffusion | 25 | 5k | done | 0.0119 | `diffusionnostateh48_n25_s5k/checkpoints/` 000500, 001000, 001500, 002000, 002500, 003000, 003500, 004000, 004500, 005000 |
| diffusion | 100 | 5k | done | 0.0138 | `diffusionnostateh48_n100_s5k/checkpoints/` 000500, 001000, 001500, 002000, 002500, 003000, 003500, 004000, 004500, 005000 |
| diffusion | 50 | 20k | done | 0.0065 | `diffusionnostateh48_n50_s20k/checkpoints/` 002000, 004000, 006000, 008000, 010000, 012000, 014000, 016000, 018000, 020000 |
| diffusion | 100 | 20k | done | 0.0090 | `diffusionnostateh48_n100_s20k/checkpoints/` 002000, 004000, 006000, 008000, 010000, 012000, 014000, 016000, 018000, 020000 |
| diffusion | 25 | 20k | done | 0.0042 | `diffusionnostateh48_n25_s20k/checkpoints/` 002000, 004000, 006000, 008000, 010000, 012000, 014000, 016000, 018000, 020000 |
| diffusion | 10 | 20k | done | 0.0030 | `diffusionnostateh48_n10_s20k/checkpoints/` 002000, 004000, 006000, 008000, 010000, 012000, 014000, 016000, 018000, 020000 |
| diffusion | 50 | 50k | done | 0.0040 | `diffusionnostateh48_n50_s50k/checkpoints/` 005000, 010000, 015000, 020000, 025000, 030000, 035000, 040000, 045000, 050000 |
| diffusion | 100 | 50k | done | 0.0061 | `diffusionnostateh48_n100_s50k/checkpoints/` 005000, 010000, 015000, 020000, 025000, 030000, 035000, 040000, 045000, 050000 |
| diffusion | 25 | 50k | done | 0.0025 | `diffusionnostateh48_n25_s50k/checkpoints/` 005000, 010000, 015000, 020000, 025000, 030000, 035000, 040000, 045000, 050000 |
| diffusion | 10 | 50k | done | 0.0019 | `diffusionnostateh48_n10_s50k/checkpoints/` 005000, 010000, 015000, 020000, 025000, 030000, 035000, 040000, 045000, 050000 |

## Runs

| run | wall time | step/s | loss start -> end |
|---|---|---|---|
| diffusionnostateh48_n50_s5k | 0.36 h | 3.84 | 0.213 -> 0.0130 |
| diffusionnostateh48_n10_s5k | 0.36 h | 3.91 | 0.216 -> 0.0080 |
| diffusionnostateh48_n25_s5k | 0.34 h | 4.12 | 0.216 -> 0.0112 |
| diffusionnostateh48_n100_s5k | 0.33 h | 4.20 | 0.215 -> 0.0134 |
| diffusionnostateh48_n50_s20k | 1.26 h | 4.40 | 0.126 -> 0.0065 |
| diffusionnostateh48_n100_s20k | 1.26 h | 4.42 | 0.127 -> 0.0090 |
| diffusionnostateh48_n25_s20k | 1.29 h | 4.29 | 0.128 -> 0.0042 |
| diffusionnostateh48_n10_s20k | 1.36 h | 4.09 | 0.129 -> 0.0030 |
| diffusionnostateh48_n50_s50k | 3.10 h | 4.57 | 0.126 -> 0.0040 |
| diffusionnostateh48_n100_s50k | 2.97 h | 4.67 | 0.127 -> 0.0061 |
| diffusionnostateh48_n25_s50k | 3.05 h | 4.55 | 0.128 -> 0.0025 |
| diffusionnostateh48_n10_s50k | 3.23 h | 4.30 | 0.129 -> 0.0019 |

## Plots

- `compare_diffusion_s5k_by_data.png`
- `compare_diffusion_s20k_by_data.png`
- `compare_diffusion_s50k_by_data.png`
- `compare_diffusion_n10_by_steps.png`
- `compare_diffusion_n25_by_steps.png`
- `compare_diffusion_n50_by_steps.png`
- `compare_diffusion_n100_by_steps.png`
- `diffusionnostateh48_n50_s5k_plot.png`
- `diffusionnostateh48_n10_s5k_plot.png`
- `diffusionnostateh48_n25_s5k_plot.png`
- `diffusionnostateh48_n100_s5k_plot.png`
- `diffusionnostateh48_n50_s20k_plot.png`
- `diffusionnostateh48_n100_s20k_plot.png`
- `diffusionnostateh48_n25_s20k_plot.png`
- `diffusionnostateh48_n10_s20k_plot.png`
- `diffusionnostateh48_n50_s50k_plot.png`
- `diffusionnostateh48_n100_s50k_plot.png`
- `diffusionnostateh48_n25_s50k_plot.png`
- `diffusionnostateh48_n10_s50k_plot.png`

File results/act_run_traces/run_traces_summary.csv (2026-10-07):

file | date | time | checkpoint | position | steps | duration_s | loop_hz | magnet_presses | mean_plan_s
20261002_213405_act_n50_s50k_050000_run1.npz | 20261002 | 213405 | act_n50_s50k_050000 |  | 251 | 8.7 | 29.5 | 2 | 0.14
20261002_213612_act_n50_s50k_050000_run2.npz | 20261002 | 213612 | act_n50_s50k_050000 |  | 1210 | 41.3 | 29.4 | 11 | 0.102
20261002_213737_act_n10_s50k_050000_run1.npz | 20261002 | 213737 | act_n10_s50k_050000 |  | 960 | 32.8 | 29.5 | 11 | 0.106
20261002_213829_act_n10_s50k_050000_run2.npz | 20261002 | 213829 | act_n10_s50k_050000 |  | 940 | 32.2 | 29.4 | 9 | 0.115
20261002_213857_act_n10_s50k_050000_run3.npz | 20261002 | 213857 | act_n10_s50k_050000 |  | 353 | 12.1 | 29.6 | 4 | 0.113
20261002_214509_act_n10_s50k_050000_run1.npz | 20261002 | 214509 | act_n10_s50k_050000 |  | 586 | 20.1 | 29.5 | 7 | 0.122
20261002_214553_act_n10_s50k_050000_run2.npz | 20261002 | 214553 | act_n10_s50k_050000 |  | 644 | 22.0 | 29.5 | 10 | 0.108
20261002_214634_act_n10_s50k_050000_run3.npz | 20261002 | 214634 | act_n10_s50k_050000 |  | 420 | 14.5 | 29.4 | 5 | 0.126
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

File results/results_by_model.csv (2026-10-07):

policy | demos | steps | checkpoint | n | successes | picked | unsafe_stops | mean_grab_attempts | success_rate | pick_rate | ci95_low | ci95_high | Dropped in transit | KnockedBoltOver | Stalled or timed out | Unsafe | success | positions_with_success
ACT | 10 | 5000 | act_n10_s50k_005000 | 10 | 0 | 0 | 10 |  | 0.0 | 0.0 | 0.0 | 0.2775401687666166 | 0 | 0 | 0 | 10 | 0
ACT | 10 | 20000 | act_n10_s50k_020000 | 10 | 0 | 0 | 2 | 6.75 | 0.0 | 0.0 | 0.0 | 0.2775401687666166 | 0 | 4 | 4 | 2 | 0
ACT | 10 | 50000 | act_n10_s50k_050000 | 10 | 0 | 0 | 0 | 5.5 | 0.0 | 0.0 | 0.0 | 0.2775401687666166 | 0 | 8 | 2 | 0 | 0
ACT | 25 | 5000 | act_n25_s50k_005000 | 10 | 0 | 1 | 2 | 4.5 | 0.0 | 0.1 | 0.0 | 0.2775401687666166 | 1 | 6 | 1 | 2 | 0
ACT | 25 | 20000 | act_n25_s50k_020000 | 10 | 6 | 6 | 0 | 1.8 | 0.6 | 0.6 | 0.3126695474501864 | 0.8318224187964902 | 0 | 4 | 0 | 0 | 6 | P1 P2 P3 P5
ACT | 25 | 50000 | act_n25_s50k_050000 | 10 | 2 | 2 | 0 | 4.0 | 0.2 | 0.2 | 0.056680947980693314 | 0.5098431532792765 | 0 | 6 | 2 | 0 | 2 | P1 P2
ACT | 50 | 5000 | act_n50_s50k_005000 | 10 | 1 | 1 | 4 | 2.5 | 0.1 | 0.1 | 0.01787574951572113 | 0.4041563854975721 | 0 | 5 | 0 | 4 | 1 | P1
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

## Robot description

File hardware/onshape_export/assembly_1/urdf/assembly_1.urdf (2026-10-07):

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
<robot name="assembly_1">
    <link name="ball_1" />
    <link name="ball_10" />
    <link name="ball_10_1" />
    <link name="ball_11" />
    <link name="ball_11_1" />
    <link name="ball_12" />
    <link name="ball_12_1" />
    <link name="ball_1_1" />
    <link name="ball_2" />
    <link name="ball_2_1" />
    <link name="ball_3" />
    <link name="ball_3_1" />
    <link name="ball_4_loop_closure" />
    <link name="ball_4_loop_closure_1" />
    <link name="ball_5" />
    <link name="ball_5_1" />
    <link name="ball_6_loop_closure" />
    <link name="ball_6_loop_closure_1" />
    <link name="ball_7" />
    <link name="ball_7_1" />
    <link name="ball_8_loop_closure" />
    <link name="ball_8_loop_closure_1" />
    <link name="ball_9" />
    <link name="ball_9_1" />
    <link name="cylindrical_1" />
    <link name="cylindrical_6" />
    <link name="parallel_2" />
    <link name="parallel_2_1" />
    <link name="parallel_2_2" />
    <link name="part_1">
        <inertial>
            <mass value="6.07059e-06" />
            <origin xyz="-8.3509e-21 -8.72066e-18 5.6798e-20" rpy="0 -0 0" />
            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
        </inertial>
        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
    </link>
    <link name="part_1_1">
        <inertial>
            <mass value="6.07059e-06" />
            <origin xyz="0.00211558 0.109027 -0.115657" rpy="-0.825947 0.143879 -0.173675" />
            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
        </inertial>
        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
    </link>
    <link name="part_1_10">
        <inertial>
            <mass value="6.07059e-06" />
            <origin xyz="-0.00192079 0.109027 -0.115661" rpy="-0.832073 0.178246 -0.174658" />
            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
        </inertial>
        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
    </link>
    <link name="part_1_11">
        <inertial>
            <mass value="0.000161462" />
            <origin xyz="-0.0328504 -0.0611292 -0.0110555" rpy="0 -0 0" />
            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
        </inertial>
        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
    </link>
    <link name="part_1_2">
        <inertial>
            <mass value="6.07059e-06" />
            <origin xyz="-0.0241861 0.0586093 0.145767" rpy="1.19606 -0.171156 -0.0172805" />
            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
        </inertial>
        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
    </link>
    <link name="part_1_3">
        <inertial>
            <mass value="4.92682e-05" />
            <origin xyz="-0.0740014 0.0233801 -1.50604e-19" rpy="0 -0 0" />
            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
        </inertial>
        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
    </link>
    <link name="part_1_4">
        <inertial>
            <mass value="0.0155576" />
            <origin xyz="0.0126323 -0.0126323 0.149693" rpy="0 -0 0" />
            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
        </inertial>
        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
    </link>
    <link name="part_1_5">
        <inertial>
            <mass value="4.92682e-05" />
            <origin xyz="0.0145466 0.0090477 0.0756926" rpy="-0.754159 1.38096 2.02453" />
            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
        </inertial>
        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
    </link>
    <link name="part_1_6">
        <inertial>
            <mass value="6.07059e-06" />
            <origin xyz="0.111357 0.0586093 -0.0971214" rpy="1.96773 -0.846655 -0.0257045" />
            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
        </inertial>
        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
    </link>
    <link name="part_1_7">
        <inertial>
            <mass value="2.71073e-05" />
            <origin xyz="-0.0137099 -0.0348369 0.000691901" rpy="0 -0 0" />
            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
        </inertial>
        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
    </link>
    <link name="part_1_8">
        <inertial>
            <mass value="6.07059e-06" />
            <origin xyz="-8.3509e-21 0.158959 5.6798e-20" rpy="0 -0 0" />
            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
        </inertial>
        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
    </link>
    <link name="part_1_9">
        <inertial>
            <mass value="4.92682e-05" />
            <origin xyz="0.0323337 -0.0324606 -0.0626392" rpy="-0.929482 -1.21037 2.044" />
            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
        </inertial>
        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
    </link>
    <link name="part_1__2__loop_closure">
        <inertial>
            <mass value="1e-09" />
            <origin xyz="0 0 0" rpy="0 -0 0" />
            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
        </inertial>
    </link>
    <link name="part_1__4__loop_closure">
        <inertial>
            <mass value="1e-09" />
            <origin xyz="0 0 0" rpy="0 -0 0" />
            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
        </inertial>
    </link>
    <link name="part_1__5__loop_closure">
        <inertial>
            <mass value="1e-09" />
            <origin xyz="0 0 0" rpy="0 -0 0" />
            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
        </inertial>
    </link>
    <link name="part_1__9__loop_closure">
        <inertial>
            <mass value="1e-09" />
            <origin xyz="0 0 0" rpy="0 -0 0" />
            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
        </inertial>
    </link>
    <link name="part_2">
        <inertial>
            <mass value="0.00016214" />
            <origin xyz="-0.000217452 -0.0147989 0.0147203" rpy="0 -0 0" />
            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
        </inertial>
        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
    </link>
    <link name="part_3">
        <inertial>
            <mass value="0.000161462" />
            <origin xyz="-0.0260943 0.0674923 -0.0178055" rpy="0 -0 0" />
            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
        </inertial>
        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
    </link>
    <link name="part_4">
        <inertial>
            <mass value="6.24351e-05" />
            <origin xyz="-6.95285e-05 -9.88357e-05 -0.00507004" rpy="0 -0 0" />
            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
        </inertial>
        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
    </link>
    <link name="part_4__1__loop_closure">
        <inertial>
            <mass value="1e-09" />
            <origin xyz="0 0 0" rpy="0 -0 0" />
            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
        </inertial>
    </link>
    <link name="part_5">
        <inertial>
            <mass value="3.72528e-05" />
            <origin xyz="-0.00493615 0.0183331 -0.00461527" rpy="0 -0.751815 0" />
            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
        </inertial>
        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
    </link>
    <link name="part_5_1">
        <inertial>
            <mass value="3.72528e-05" />
            <origin xyz="0.00616171 0.0203331 0.00277483" rpy="3.14159 0.423132 3.14159" />
            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
        </inertial>
        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
    </link>
    <link name="part_5_2">
        <inertial>
            <mass value="3.72528e-05" />
            <origin xyz="-0.00675769 0.0203331 0" rpy="0 -0 0" />
            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
        </inertial>
        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
    </link>
    <link name="part_5__3__loop_closure">
        <inertial>
            <mass value="1e-09" />
            <origin xyz="0 0 0" rpy="0 -0 0" />
            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
        </inertial>
    </link>
    <link name="planar_1" />
    <link name="planar_12_loop_closure" />
    <link name="planar_12_loop_closure_1" />
    <link name="planar_15_loop_closure" />
    <link name="planar_15_loop_closure_1" />
    <link name="planar_18" />
    <link name="planar_18_1" />
    <link name="planar_19" />
    <link name="planar_19_1" />
    <link name="planar_1_1" />
    <link name="planar_3" />
    <link name="planar_3_1" />
    <link name="planar_6_loop_closure" />
    <link name="planar_6_loop_closure_1" />
    <link name="planar_9" />
    <link name="planar_9_1" />
    <link name="root" />
    <joint name="ball_1" type="continuous">
        <origin xyz="0.222713 0.117219 -0.194243" rpy="1.80961 -1.16056 -3.10793" />
        <axis xyz="1 0 0" />
        <parent link="part_1_6" />
        <child link="ball_1_1" />
    </joint>
    <joint name="ball_10" type="continuous">
        <origin xyz="-0.0508 -0.0404956 2.77556e-17" rpy="-2.37752 -0.191553 1.59311" />
        <axis xyz="1 0 0" />
        <parent link="part_1_7" />
        <child link="ball_10_1" />
    </joint>
    <joint name="ball_10_1" type="continuous">
        <origin xyz="0 0 0" rpy="0 -0 0" />
        <axis xyz="0 1 0" />
        <parent link="ball_10_1" />
        <child link="ball_10" />
    </joint>
    <joint name="ball_10_2" type="continuous">
        <origin xyz="0 0 0" rpy="0 -0 0" />
        <axis xyz="0 0 1" />
        <parent link="ball_10" />
        <child link="part_1_2" />
    </joint>
    <joint name="ball_11" type="continuous">
        <origin xyz="0.00967019 -0.0642419 -9.71445e-16" rpy="-1.53807 -0.0583253 0.166992" />
        <axis xyz="1 0 0" />
        <parent link="part_1_7" />
        <child link="ball_11_1" />
    </joint>
    <joint name="ball_11_1" type="continuous">
        <origin xyz="0 0 0" rpy="0 -0 0" />
        <axis xyz="0 1 0" />
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

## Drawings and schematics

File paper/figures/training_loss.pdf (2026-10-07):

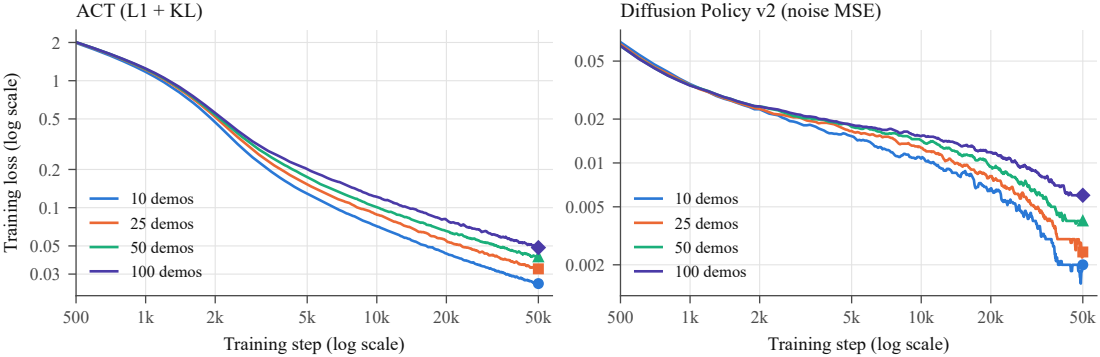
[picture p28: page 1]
ACT (L1 + KL); 10 demos 25 demos 50 demos 100 demos

Diffusion Policy v2 (noise MSE)

Training loss (log scale)

Training step (log scale)

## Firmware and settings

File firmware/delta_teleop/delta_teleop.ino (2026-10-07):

/*
 * Delta Robot - TELEOPERATION + AUTONOMOUS firmware (Teensy 4.1)
 *
 * Leader   : 3x AS5600 magnetic encoders on a hand-moved leader arm.
 * Follower : 3x Feetech STS3215 servos on Serial1 (1 Mbit/s).
 * In RECORD mode the Teensy reads the leader angles, commands the servos to match, reads the
 * servos back, and streams both over USB serial as CSV. In AUTO mode the host (the policy)
 * sends joint targets + the magnet command instead.
 *
 * Serial protocol (USB, 115200, newline-terminated) -- used by robot/record_demos.py,
 * robot/run_policy.py and robot/teensy_check.py:
 *
 *   Host -> Teensy:
 *     s                     start RECORD mode  (servos mirror the leader)
 *     a                     start AUTONOMOUS mode (host sends commands)
 *     c,<a1>,<a2>,<a3>[,m]  in AUTO mode: drive the 3 servos to these angles (deg); m = magnet 0/1
 *     x                     stop (go idle)
 *     d                     one-shot DEBUG dump (encoders + button/magnet state)
 *
 *   Electromagnet: a button shorting GPIO4<->GPIO5 energizes an electromagnet on the follower,
 *   driven through an H-bridge (IN1=pin30, IN2=pin32). MOMENTARY: button pressed = magnet ON
 *   (grab), released = OFF. In AUTO mode the host owns the magnet.
 *
 *   Teensy -> Host (while streaming, STREAM_HZ = 60):
 *     <millis>,<lead1>,<lead2>,<lead3>,<foll1>,<foll2>,<foll3>,<mag>
 *       - action  = leader  (fields 1..3)   <- what you commanded by hand
 *       - state   = follower(fields 4..6)   <- where the servos actually are
 *       - mag     = field 7 (0=off, 1=on)   <- electromagnet state
 *     A failed read is streamed as -999 (the host skips those frames). In AUTO mode the leader
 *     encoders are not read (they may be unplugged) and stream as -999.
 *
 * Units: leader and follower are both in DEGREES (90 deg = the calibration reference pose).
 * Every servo command is clamped to DEG_MIN..DEG_MAX.
 */

#include <SCServo.h>
#include <Wire.h>
#include <SoftWire.h>   // Steve Marple's "SoftWire" (Arduino Library Manager)

// ============================================================
//  SERVOS (follower)
// ============================================================
#define SERVO_SERIAL Serial1          // TX=pin1, RX=pin0 on Teensy 4.1
#define SERVO_BAUD   1000000
SMS_STS sms_sts;

const int   SERVO_IDS[3]        = {2, 3, 1};
const int   NINETY_DEG_UNITS[3] = {2101, 2012, 2012};   // servo units at 90 deg, per servo  *** CALIBRATE ME ***
const float UNITS_PER_DEG       = 4096.0 / 360.0;
const int   MOVE_SPEED          = 1500;                  // responsive teleop tracking
const int   MOVE_ACCEL          = 50;

int   degToUnits(float deg, int s) { return (int)round((deg - 90.0) * UNITS_PER_DEG + NINETY_DEG_UNITS[s]); }
float unitsToDeg(int u,   int s)   { return (u - NINETY_DEG_UNITS[s]) / UNITS_PER_DEG + 90.0; }

// ============================================================
//  ENCODERS (leader) -- 3x AS5600, one per I2C bus
//  All AS5600 share address 0x36, so each needs its own bus.
//  Two live on hardware I2C; one moved to a bit-banged SoftWire
//  bus after a hardware pin broke on the original wiring.
// ============================================================
#define AS5600_ADDR         0x36
#define AS5600_RAW_ANGLE_HI 0x0C     // RAW ANGLE register (0x0C hi, 0x0D lo), 12-bit

// ---- BUS ASSIGNMENT --------------------------------------  *** EDIT ME ***
// Encoders 0 and 1 on the two still-working hardware buses.
// Teensy 4.1 hardware I2C buses are: Wire, Wire1, Wire2.
TwoWire* HW_BUS[2] = { &Wire, &Wire2 };   // <-- set to your two working buses

// Encoder 2 on SoftWire.                                     *** SET THESE PINS ***
#define SOFT_SDA  20                 // <-- CHANGE to your SoftWire SDA pin
#define SOFT_SCL  21                 // <-- CHANGE to your SoftWire SCL pin
SoftWire  soft(SOFT_SDA, SOFT_SCL);
uint8_t   softTx[8], softRx[8];

// ---- PER-ENCODER CALIBRATION ------------------------------  *** CALIBRATE ME ***
// Run the 'd' command with each joint held at REF_DEG, read the raw counts it
// prints, and paste them into RAW_AT_REF. Flip a DIR sign if that joint reads
// backwards (degrees go down when the arm goes up).
int   RAW_AT_REF[3] = { 1672, 1519, 2968 };     // raw 0..4095 when the joint is at REF_DEG
int   DIR[3]        = { -1, -1, -1 };  // +1 or -1 per joint
float REF_DEG       = 90.0;            // the angle you hold each joint at to calibrate

// ---- SAFETY: clamp every servo command to a safe joint range ----
const float DEG_MIN = 30.0;
const float DEG_MAX = 110.0;

// ============================================================
//  BUTTON + ELECTROMAGNET
//  A momentary button shorts BTN_DRIVE to BTN_SENSE. BTN_DRIVE is
//  driven LOW and BTN_SENSE uses the internal pull-up, so a press
//  reads LOW. The magnet is ON while the button is held (debounced),
//  driven through an H-bridge (IN1 HIGH + IN2 LOW = ON).
// ============================================================
#define BTN_DRIVE 4          // driven LOW; button shorts this to BTN_SENSE
#define BTN_SENSE 5          // INPUT_PULLUP; reads LOW when pressed
#define MAG_IN1   30         // H-bridge IN1 (HIGH = magnet on)
#define MAG_IN2   32         // H-bridge IN2 (held LOW)
const uint32_t BTN_DEBOUNCE_MS = 40;

// Operating mode (declared here so updateButton can see it): the button owns the
// magnet in RECORD/IDLE, but the host/policy owns it in AUTO.
enum Mode { IDLE, RECORD, AUTO };
Mode mode = IDLE;

bool     magOn           = false;   // current electromagnet state
int      btnStable       = HIGH;    // debounced level (HIGH = released)
int      btnLastRead     = HIGH;
uint32_t btnLastChangeMs = 0;

void setMagnet(bool on) {
  magOn = on;
  digitalWrite(MAG_IN1, on ? HIGH : LOW);
  digitalWrite(MAG_IN2, LOW);
}

// Poll the button (debounced). Momentary: magnet follows the button —
// pressed = ON, released = OFF (no toggle / flip-flop).
void updateButton() {
  if (mode == AUTO) return;                  // in AUTO the host (policy) owns the magnet
  int r = digitalRead(BTN_SENSE);
  if (r != btnLastRead) { btnLastRead = r; btnLastChangeMs = millis(); }
  if ((millis() - btnLastChangeMs) >= BTN_DEBOUNCE_MS && r != btnStable) {
    btnStable = r;
    setMagnet(btnStable == LOW);             // pressed (LOW) = ON, released = OFF
    Serial.print("# MAGNET "); Serial.println(magOn ? "ON" : "OFF");
  }
}

// ============================================================
//  Encoder read (templated so hardware TwoWire and SoftWire
//  share one code path -- both expose the standard Wire API).
// ============================================================
template <class WIRE>
int readRawAngle(WIRE &w) {
  w.beginTransmission(AS5600_ADDR);
  w.write(AS5600_RAW_ANGLE_HI);
  if (w.endTransmission(false) != 0) return -1;          // repeated start
  if (w.requestFrom((uint8_t)AS5600_ADDR, (uint8_t)2) != 2) return -1;
  int hi = w.read();
  int lo = w.read();
  return ((hi << 8) | lo) & 0x0FFF;                       // 12-bit
}

int rawEncoder(int i) {
  if (i < 2) return readRawAngle(*HW_BUS[i]);
  return readRawAngle(soft);
}

// raw counts -> degrees, using per-encoder calibration, with wraparound.
float encoderDeg(int i) {
  int raw = rawEncoder(i);
  if (raw < 0) return NAN;
  int d = raw - RAW_AT_REF[i];
  if (d >  2048) d -= 4096;
  else if (d < -2048) d += 4096;
  return DIR[i] * d * (360.0 / 4096.0) + REF_DEG;
}

float followerDeg(int i) {
  int u = sms_sts.ReadPos(SERVO_IDS[i]);
  return (u == -1) ? NAN : unitsToDeg(u, i);
}

float clampDeg(float d) {
  if (d < DEG_MIN) return DEG_MIN;
  if (d > DEG_MAX) return DEG_MAX;
  return d;
}

void driveServos(float d0, float d1, float d2) {
  float t[3] = { clampDeg(d0), clampDeg(d1), clampDeg(d2) };
  for (int i = 0; i < 3; i++)
    sms_sts.WritePosEx(SERVO_IDS[i], degToUnits(t[i], i), MOVE_SPEED, MOVE_ACCEL);
}

// ============================================================
//  Streaming
// ============================================================
const uint32_t STREAM_HZ = 60;                 // Python takes the newest line at 30 Hz
const uint32_t STREAM_US = 1000000UL / STREAM_HZ;
uint32_t lastStreamUs = 0;

void printVal(float v) {
  if (isnan(v)) Serial.print("-999");
  else          Serial.print(v, 2);
}

void streamFrame(float l0, float l1, float l2, float f0, float f1, float f2, int mag) {
  Serial.print(millis()); Serial.print(',');
  printVal(l0); Serial.print(',');
  printVal(l1); Serial.print(',');
  printVal(l2); Serial.print(',');
  printVal(f0); Serial.print(',');
  printVal(f1); Serial.print(',');
  printVal(f2); Serial.print(',');
  Serial.println(mag);
}

// ============================================================
//  Modes + command parsing
// ============================================================

void debugDump() {
  Serial.println("# DEBUG raw encoder counts (hold joints at REF_DEG, paste into RAW_AT_REF):");
  for (int i = 0; i < 3; i++) {
    int raw = rawEncoder(i);
    Serial.print("#  enc "); Serial.print(i);
    Serial.print("  raw="); Serial.print(raw);
    Serial.print("  deg="); Serial.print(encoderDeg(i), 2);
    Serial.print("  servo_deg="); Serial.println(followerDeg(i), 2);
  }
  Serial.print("#  button="); Serial.print(digitalRead(BTN_SENSE) == LOW ? "PRESSED" : "released");
  Serial.print("  magnet=");  Serial.println(magOn ? "ON" : "OFF");
}

void handleCommand(String line) {
  line.trim();
  if (line.length() == 0) return;

  if (line == "s") { mode = RECORD; return; }
  if (line == "a") { mode = AUTO;   return; }
  if (line == "x") { mode = IDLE;   return; }
  if (line == "d") { debugDump();   return; }

  if (line.startsWith("c")) {                    // c,a1,a2,a3[,m]  (autonomous drive)
    float v[4] = { NAN, NAN, NAN, NAN };         // v[3] = optional magnet (0/1)
    int start = line.indexOf(',');
    for (int i = 0; i < 4 && start != -1; i++) {
      int nxt = line.indexOf(',', start + 1);
      String tok = (nxt == -1) ? line.substring(start + 1)
                               : line.substring(start + 1, nxt);
      v[i] = tok.toFloat();
      start = nxt;
    }
    if (!isnan(v[0]) && !isnan(v[1]) && !isnan(v[2]))
      driveServos(v[0], v[1], v[2]);
    if (!isnan(v[3]))                            // policy-controlled magnet in AUTO
      setMagnet(v[3] > 0.5);
    return;
  }
}

// ============================================================
void setup() {
  Serial.begin(115200);                 // USB to laptop
  SERVO_SERIAL.begin(SERVO_BAUD);       // servo bus
  sms_sts.pSerial = &SERVO_SERIAL;
  sms_sts.IOTimeOut = 5;                // ms. Default is 100: a servo that fails to reply
                                        // stalls the loop 100ms PER read (3/frame = 300ms).
                                        // Fail fast so noise from the magnet can't crater the rate.

  for (int i = 0; i < 2; i++) { HW_BUS[i]->begin(); HW_BUS[i]->setClock(400000); }

  soft.setTxBuffer(softTx, sizeof(softTx));
  soft.setRxBuffer(softRx, sizeof(softRx));
  soft.setDelay_us(3);
  soft.begin();

  // Button + electromagnet
  pinMode(BTN_DRIVE, OUTPUT); digitalWrite(BTN_DRIVE, LOW);   // acts as GND for the button
  pinMode(BTN_SENSE, INPUT_PULLUP);                           // reads LOW when pressed
  pinMode(MAG_IN1, OUTPUT);
  pinMode(MAG_IN2, OUTPUT);
  setMagnet(false);                                          // start with the magnet off

  delay(200);
  Serial.println("READY");
}

void loop() {
  // ---- handle incoming commands (line-based) ----
  static String buf;
  while (Serial.available()) {
    char c = Serial.read();
    if (c == '\n')      { handleCommand(buf); buf = ""; }
    else if (c != '\r') { buf += c; }
  }

  updateButton();                        // poll button; magnet = pressed state (works in every mode)

  if (mode == IDLE) return;

  // ---- paced streaming ----
  uint32_t now = micros();
  if ((uint32_t)(now - lastStreamUs) < STREAM_US) return;
  lastStreamUs = now;

  float lead[3], foll[3];
  // The leader is unused in AUTO, and reading an unplugged encoder can stall the loop
  // (floating I2C lines, no timeout), so skip it there. Streams -999 for the leader.
  for (int i = 0; i < 3; i++) lead[i] = (mode == AUTO) ? NAN : encoderDeg(i);

  if (mode == RECORD) {
    // servos mirror the leader; skip any joint whose encoder failed
    for (int i = 0; i < 3; i++)
      if (!isnan(lead[i])) sms_sts.WritePosEx(SERVO_IDS[i], degToUnits(clampDeg(lead[i]), i), MOVE_SPEED, MOVE_ACCEL);
  }
  // in AUTO mode the servos are driven by incoming 'c,...' commands instead.

  for (int i = 0; i < 3; i++) foll[i] = followerDeg(i);
  streamFrame(lead[0], lead[1], lead[2], foll[0], foll[1], foll[2], magOn ? 1 : 0);
}

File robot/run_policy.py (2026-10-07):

"""
run_policy.py -- run a trained checkpoint on the delta robot, and run scored evaluation sessions.

Works on Windows (DirectShow cameras, COM port) and Linux (V4L2 cameras, /dev/tty*), CPU or GPU.
This is the script used for every robot trial in the study (the Windows copy ran ACT on a laptop
CPU, the Linux copy ran Diffusion on an RTX 3090; they were merged afterwards with the logic unchanged).

Quick start (from inside robot/):

  python run_policy.py dry --ckpt path/to/pretrained_model
      Live cameras + joint state through the policy; prints the actions. The robot is put in AUTO
      mode but NO commands are sent, so the servos just hold. Always do this first.

  python run_policy.py try --ckpt path/to/pretrained_model
      Run the policy on the robot as many times as you like (Enter = run, SPACE = stop the run).
      Type another checkpoint path at the prompt to switch models. Saves a trace per run.

Study workflow (checkpoints named like act_n50_s50k_005000 inside CKPT_DIR):

  python run_policy.py plan --name act --policies act --positions 10
      -> test_results/plan_act.csv : every checkpoint x every bolt position, seeded random order.
  python run_policy.py run --plan test_results/plan_act.csv [--blind]
      -> walks the plan, you score each trial. Resumable. Ctrl+C = safe stop.
  python run_policy.py summary
      -> success-rate table per cell + test_results/summary.png

Options (environment variables; the Diffusion ones are logged in the `inference` column):
  DELTA_PORT=COM3 | /dev/ttyACM0     Teensy serial port (default: COM3 on Windows, /dev/ttyACM0 on Linux)
  DELTA_CKPT_DIR=checkpoints         folder holding <run>_<step> checkpoint folders (study workflow)
  TC_DEVICE=cpu|cuda                 default: cuda if available
  TC_SCHED=DDPM TC_STEPS=0           Diffusion sampler. DDPM with all 100 steps is what the study used
                                     (~0.76 s per plan on an RTX 3090). On a CPU use TC_SCHED=DDIM
                                     TC_STEPS=10 (~2 s per plan; matched DDPM-100 within ~1 deg offline).
  TC_MATCH_TRAINING_CAMERAS=0        Linux only: leave the cameras on auto instead of reproducing the
                                     study's camera settings (do this for models trained on your own data).

Diffusion checkpoints trained with BLIND_STATE=1 (training/lerobot_train_fixed.py) get their joint-state
input zeroed here too. That happens automatically when the checkpoint holds a file named BLIND_STATE (the
published Diffusion checkpoint has one), when "nostate" appears in its path or in the training run's
output_dir (train_config.json), or when you set TC_BLIND_STATE=1. Diffusion runs print which applies.

Results: test_results/results.csv (one row per trial) and test_results/traces/*.npz (state, action,
timing per step).
"""

import argparse
import csv
import datetime as dt
import glob
import json
import os
import random
import re
import sys
import threading
import time

import av
import av.logging
av.logging.set_level(av.logging.ERROR)
import numpy as np
import torch

# =================== Config ===================
SERIAL_PORT = os.environ.get("DELTA_PORT", "COM3" if sys.platform.startswith("win") else "/dev/ttyACM0")
BAUD        = 115200
FPS         = 30
IMG_W, IMG_H = 320, 240

CKPT_DIR    = os.environ.get("DELTA_CKPT_DIR", "checkpoints")
RESULTS_DIR = "test_results"
RESULTS_CSV = os.path.join(RESULTS_DIR, "results.csv")
DEVICE      = os.environ.get("TC_DEVICE", "cuda" if torch.cuda.is_available() else "cpu")
MATCH_TRAINING_CAMERAS = os.environ.get("TC_MATCH_TRAINING_CAMERAS", "1") == "1"

SERVO_MIN_DEG = 30.0        # match firmware DEG_MIN/DEG_MAX
SERVO_MAX_DEG = 110.0
MAGNET_THRESHOLD = 0.5

# Mean starting follower pose of the 100 dataset demos (std ~3.5 deg per joint).
# Every trial starts here so all checkpoints see the same initial state.
START_POSE  = (91.7, 93.2, 90.8)
SETTLE_SEC  = 1.5           # time to glide to START_POSE and settle before the policy starts
MAX_SEC     = 30.0          # trial timeout in seconds of robot motion (= 900 actions); demos took 8-17 s

# Diffusion inference setting. ("DDPM", None) = exactly as trained, 100 denoising steps: what the
# study used, on an RTX 3090 (~0.76 s per 24-action plan). ("DDIM", 10) = ~2 s per plan on a laptop
# CPU; offline it matched DDPM-100 within ~0.5-1 deg. Either way the robot pauses while a plan is
# computed (fine for this quasi-static task). Keep it the SAME for every checkpoint you compare.
DIFFUSION_SCHEDULER = os.environ.get("TC_SCHED", "DDPM")
DIFFUSION_STEPS     = int(os.environ.get("TC_STEPS", "0")) or None

# Opt-in kick-start for Diffusion (see _trial_loop). Demo openings: median -10 deg on all joints in
# the first 0.33 s of motion (95% of episodes move all three joints the same way).
KICK_DEG   = float(os.environ.get("TC_KICK_DEG", "0"))
KICK_SEC   = float(os.environ.get("TC_KICK_SEC", "0.33"))
KICK_STEPS = max(1, round(KICK_SEC * FPS))

# Opt-in Diffusion anti-jitter settings (logged in the `inference` column):
#  TC_ACTION_STEPS=16 : execute 16 actions per plan instead of the trained default 8 (fewer replans)
#  TC_FIXED_NOISE=1   : start every plan from the same initial noise -> consecutive plans agree
ACTION_STEPS = int(os.environ.get("TC_ACTION_STEPS", "0")) or None
FIXED_NOISE  = os.environ.get("TC_FIXED_NOISE", "0") == "1"

STALE_SEC = 0.5

RESULT_FIELDS = ["timestamp", "plan", "plan_order", "checkpoint", "policy", "n_episodes", "steps",
                 "position", "valid", "picked", "success", "failure_mode", "duration_s",
                 "end_reason", "magnet_presses", "n_plans", "mean_plan_s", "max_plan_s", "inference", "notes"]

FAILURE_MODES = {
    "1": "no_pick",          # never got the bolt on the magnet
    "2": "dropped",          # picked, lost it before the bucket
    "3": "missed_bucket",    # released, but not in the bucket
    "4": "stalled",          # froze / wandered / timed out without finishing
    "5": "unsafe",           # erratic motion, operator stopped it
    "6": "other",
}


def parse_ckpt_name(name):
    """act_n50_s50k_005000 -> ('act', 50, 5000). Variants keep their prefix as the policy name,
    e.g. diffusionnostateh48_n50_s5k_005000 -> ('diffusionnostateh48', 50, 5000), so results never
    mix. Any other name (e.g. a downloaded checkpoint path) -> (folder name, 0, 0)."""
    base = os.path.basename(os.path.normpath(name))
    m = re.match(r"((?:act|diffusion)[a-z0-9]*)_n(\d+)_s\d+k_(\d+)$", base)
    if not m:
        return base, 0, 0
    return m.group(1), int(m.group(2)), int(m.group(3))


def ckpt_path(name):
    """A checkpoint is either a folder path, or a folder name inside CKPT_DIR."""
    return name if os.path.isdir(name) else os.path.join(CKPT_DIR, name)
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
